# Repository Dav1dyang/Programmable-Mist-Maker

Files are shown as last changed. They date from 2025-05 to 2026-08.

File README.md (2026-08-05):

# Programmable Mist Maker

**Open-source, programmable ultrasonic mist maker kits** — by
[shuang cai](https://shuangcai.cargo.site/) & [David Yang](https://davidyang.work/) at ByProduct Lab.

📖 **[Documentation](https://docs.byproductlab.com/)** ·
🛒 **[Buy a kit](https://shop.byproductlab.com)** ·
📜 [OSHWA certified US002742](https://certification.oshwa.org/us002742.html) ·
✍️ [Build story on Hackster](https://www.hackster.io/dav1dyang/waste-into-wonder-making-programmable-mist-makers-fe3ae7)

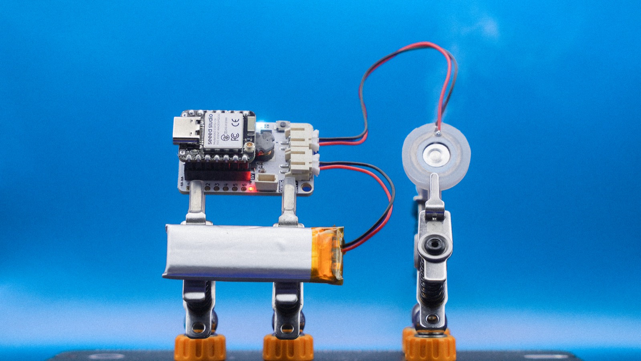
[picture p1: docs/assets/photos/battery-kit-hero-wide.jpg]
A Battery Kit board with a XIAO ESP32-C6 and a Li-Po cell, driving a piezo disc that is actively misting


Most mist-maker circuits online are undocumented black boxes. This project fills that
gap: tested reference circuits, full KiCad sources, an Arduino library, and honest
notes about what went wrong along the way — so creators, educators, and engineers can
explore mist as a material. First presented as a hands-on workshop at the
**Open Hardware Summit 2025**.

## The boards

| Board | Power | Best for | Status |
|---|---|---|---|
| [**Extension Kit**](variants/xiao-extension-kit/) | USB-C | First builds, desks, classrooms | V0.1 — hardware + firmware ready |
| [**Battery Kit**](variants/battery-kit/) | Li-Po + USB-C | Portable builds, installations | **V0.4.1 — in production, bench-validated** |
| [**Block Kit**](variants/block-kit/) | Li-Po + USB-C | Drop-in container UX, 14 LEDs | V0.1 — demoed at OHS 2026 |
| [**I2C MultiPack**](variants/i2c-multipack-kit/) | TBD | Multi-emitter installations | In design |
| [**Legacy V1.4**](legacy/v1-4/) | USB / Li-Po | Reproducing the original workshop kit | Shipped, frozen |

<p align="center">
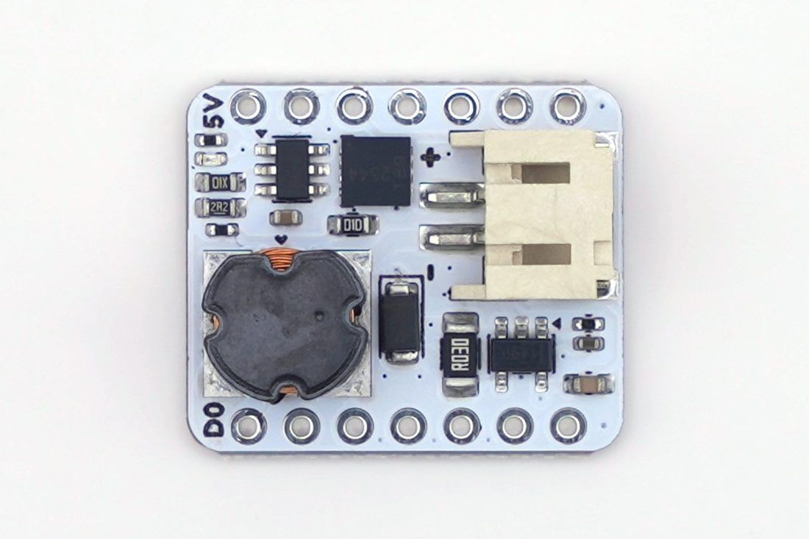
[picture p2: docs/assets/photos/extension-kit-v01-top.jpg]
Extension Kit V0.1, top side
  
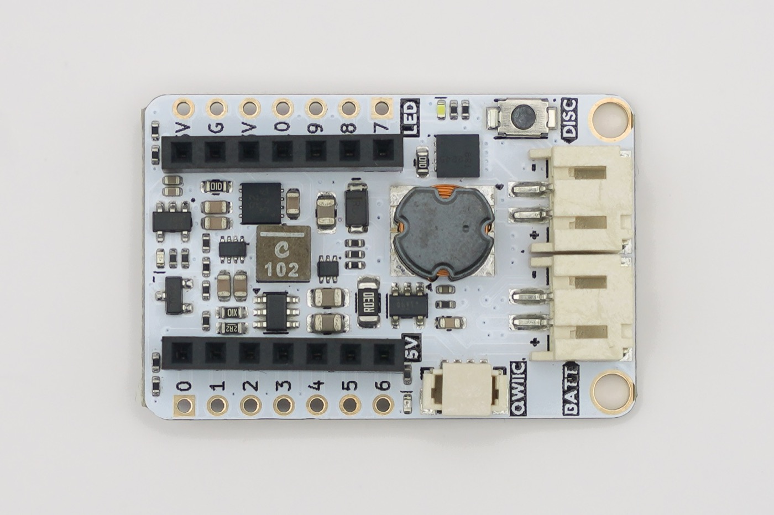
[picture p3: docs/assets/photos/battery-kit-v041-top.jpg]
Battery Kit V0.4.1, top side
  
</p>

<p align="center"><em>The two shipping boards: Extension Kit V0.1 (left) and Battery Kit V0.4.1 (right).</em></p>

Each variant folder has its own README with pin maps, an order-ready BOM + JLCPCB
production files, and build instructions. Board-by-board guides with **interactive
schematics** live on the [documentation site](https://docs.byproductlab.com/).

## Start here

1. **Pick a board** — the [Extension Kit](https://docs.byproductlab.com/boards/extension-kit/)
   is the easiest first build; the [Battery Kit](https://docs.byproductlab.com/boards/battery-kit/)
   cuts the cord. (Or [buy one assembled and tested](https://shop.byproductlab.com).)
2. **Flash the variant's BringUp sketch** to verify the hardware feature by feature.
3. **Install the [MistMaker Arduino library](https://github.com/owochel/MistMaker)** (v2.2+)
   and work through the examples: `Blink` → `Breath` → `WaterDetect` →
   `PhoneDemo` (control it from your phone).
4. **Smart home?** [`firmware-examples/home-assistant/`](firmware-examples/home-assistant/)
   joins Home Assistant with no code at all (ESPHome).

## How it works

An ESP32 drives a piezo disc at its **108.7 kHz** resonance through a MOSFET and a
3-legged tapped inductor — an autotransformer + LC tank that steps 5 V up to the
~80 Vpp the disc needs, while a current-sense amp lets the firmware detect the
disc and the water level on one ADC pin. The full story — atomization science, why
that strange inductor is everywhere in Shenzhen and nowhere at DigiKey, and a
verified alternative circuit — is at
[docs.byproductlab.com/how-it-works](https://docs.byproductlab.com/how-it-works/).

## Repo map

| Path | Contents |
|---|---|
| `variants/<board>/` | Per-board KiCad project, BOM, production files, BringUp firmware, enclosure |
| `legacy/v1-4/` | The original workshop kit, preserved as documented (incl. duck & UFO enclosure STLs) |
| `firmware-examples/` | ESPHome / Home Assistant configs |
| `docs/` | The [documentation site](https://docs.byproductlab.com/) (MkDocs), incl. `docs/assets/photos/` |
| `assets/` | Legacy V1.4 photos and the design-progress GIFs |

> [!NOTE]
> Reproducing the **legacy V1.4 board**? It has a few quirks the V0.x boards designed
> away (power sequencing, upload-while-misting) — fixes are preserved on the
> [Legacy V1.4 docs page](https://docs.byproductlab.com/boards/legacy-v1-4/).

## Use and care

> [!WARNING]
> Water + electronics + time = biology. Use distilled or clean tap water, clean the
> container regularly, and let cotton sticks dry between uses. Never run a disc
> dry for long, and never drive the circuit without a disc attached. Full notes in the
> [docs](https://docs.byproductlab.com/how-it-works/#use-and-care).

## License & credits

Open source under the **MIT License**, certified open source hardware
([OSHWA US002742](https://certification.oshwa.org/us002742.html)). Designed and
tested by [David Yang](https://davidyang.work/) and
[shuang cai](https://shuangcai.cargo.site/), inspired by community
reverse-engineering and YouTube teardowns — full reference list in the
[docs](https://docs.byproductlab.com/how-it-works/#research-references).

Parts of the documentation were drafted with AI assistance; all technical content is
validated against bench measurements and datasheets.

**Contact:** [contact@byproductlab.com](mailto:contact@byproductlab.com) ·
[@dav1dyang](https://www.instagram.com/dav1dyang/)

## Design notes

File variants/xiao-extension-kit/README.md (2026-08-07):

# Xiao Extension Kit — V0.1

The simplest way to drive mist from a [Seeed XIAO ESP32-C6](https://www.seeedstudio.com/Seeed-Studio-XIAO-ESP32C6-Pre-Soldered-p-6328.html): an expansion PCB that mounts directly on the XIAO. USB-C powered, no battery, no boost converter — just the piezo drive stage and an INA180 current-sense amp so your code can *feel* the disc working.

Great for: desks, breadboard experiments, classrooms, and anyone's first mist build.

📖 **[Full guide with interactive schematic](https://docs.byproductlab.com/boards/extension-kit/)** ·
🛒 **[Buy it assembled](https://shop.byproductlab.com/kits/extension-kit)**

Extension Kit V0.1, top side: tapped inductor bottom-left, PH-2.0 piezo connector on the right, header rows top and bottom

## What's in this folder

| Subfolder | Contents |
|---|---|
| [`hardware/`](hardware/) | KiCad project, schematic/assembly PDFs, BOM, JLCPCB production files |
| [`firmware/ExtensionKit_BringUp/`](firmware/ExtensionKit_BringUp/) | Per-feature test sketch — flash this first on a new board |
| `enclosure/` | 3D-printable demo enclosure (not published yet) |

## How it works

```
XIAO USB-C 5V ──┬─► UCC27511 gate driver ─► DMT10H009 MOSFET ─► 3-leg inductor ─► piezo disc
                │         ▲ D0: 108.7 kHz PWM                     (LC resonance boosts
                └─► 30 mΩ shunt ─► INA180A3 ─► D2 (analog)          5 V to ~80 Vpp)
```

- The ESP32 outputs a **108.7 kHz PWM** (the disc's resonant frequency) at 33% duty by default — the thermal sweet spot, not a hard ceiling ([why](https://docs.byproductlab.com/how-it-works/#the-resonant-drive-5-v-in-80-vpp-out)).
- The MOSFET switches the tapped-inductor + piezo loop; LC resonance boosts the 5 V rail to the ~80 Vpp the disc needs (measured on the Legacy V1.4 circuit; same topology here).
- The **INA180A3** (100 V/V) reads the voltage across a 30 mΩ shunt — 3.0 V per amp into D2. A dry disc draws visibly less than a wet one, which is how disc-presence and water-level detection work.

## Pin map

| XIAO pin | Net | Function |
|---|---|---|
| D0 | `MIST_PWM_3V3` | 108.7 kHz PWM to gate driver |
| D2 | `CS` | INA180A3 current-sense output (3.0 V/A) |
| D4 / D5 | SDA / SCL | I2C breakout — free for your sensors |

## Key components ([full BOM](hardware/production/bom.csv))

| Part | Role |
|---|---|
| UCC27511A gate driver | Clean, fast MOSFET gate edges at 108.7 kHz |
| DMT10H009LCG MOSFET | Switches the resonant loop |
| 3-legged tapped inductor (CD75) | LC voltage boost to ~80 Vpp |
| INA180A3 + 30 mΩ shunt | Analog current sense (3.0 V/A) |
| PH-2.0 connector | Piezo disc |

## Build your own

1. Order PCBs with the JLCPCB production files in [`hardware/`](hardware/) (SMT assembly recommended — everything except the connectors can be machine-placed).
2. Solder the PH-2.0 piezo connector and XIAO headers.
3. Mount a XIAO ESP32-C6.
4. Flash [`firmware/ExtensionKit_BringUp/`](firmware/ExtensionKit_BringUp/) and walk its serial checklist (`h` for help).
5. Install the [MistMaker library](https://github.com/owochel/MistMaker) (v2.2+) and try the examples: `Blink` → `Breath` → `WaterDetect` → `PhoneDemo`.

In library examples select the board with:

```cpp
MistMaker mist(MistMakerExtensionV01());
```

## Notes

- Power budget: a misting disc draws roughly 0.3–0.5 A from the 5 V USB rail — any normal USB port or charger is fine.
- Safety, cleaning, and known-issues notes live in the [root README](../../README.md).

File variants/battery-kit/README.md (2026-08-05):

# Battery Kit — V0.4.1

The portable, single-PCB "grab and go" Mist Maker: Li-Po battery + USB-C charging, full power path, piezo drive, current sensing, a button, a status LED — and **trustworthy battery monitoring**: since V0.4 the board routes the power mux's status pin to the XIAO (D8), so firmware knows whether it is running from USB or the cell and low-battery logic can never false-trigger while plugged in.

> **V0.4.1** is the July 2026 production revision (the boards in the shop): R22 → 220 kΩ widens the D8 USB-detect margin, R8 → pull-down means the ~5 V rail boots **off** (and deep sleep drops to ~0.25 mA), R7 → 5.1 kΩ dims LED2. Same pin map as V0.4. The [`hardware/`](hardware/) folder holds the as-fabbed V0.4.1 KiCad + production files, the design-review memos, and the acceptance-test protocol.

Great for: installations, performances, kits, and anywhere without a USB cable.

📖 **[Full guide with interactive schematic](https://docs.byproductlab.com/boards/battery-kit/)** ·
🧰 **[Enclosure & assembly](https://docs.byproductlab.com/boards/battery-kit-enclosure/)** ·
🛒 **[Buy it assembled](https://shop.byproductlab.com/kits/battery-kit)**

Battery Kit V0.4.1, top side: tapped inductor at center, QWIIC / DISC / BATT connectors and the button along the right edge

## What's in this folder

| Subfolder | Contents |
|---|---|
| [`hardware/`](hardware/) | As-fabbed V0.4.1 KiCad project, schematic PDF, BOM, JLCPCB production files, design reviews + acceptance protocol |
| [`firmware/BatteryKit_BringUp/`](firmware/BatteryKit_BringUp/) | Bring-up sketch — flash first; hold the button ≥ 1.5 s for the **automated self-test** |
| [`firmware/DutySweep_Test/`](firmware/DutySweep_Test/) | Duty→current characterization tool (the data behind the 50% default) |
| `enclosure/` | 3D-printable demo enclosure — print files not published yet; the build is documented step by step in [Enclosure & Assembly](https://docs.byproductlab.com/boards/battery-kit-enclosure/) |

## How it works

```
USB-C ─► LP4060 charger ─► Li-Po ─┐
                                  ├─► TPS2116 power mux ─► AP7361C 3V3 LDO ─► XIAO
USB-C 5V ─────────────────────────┘
                                  └─► TPS61023 boost (EN = D3) ─► 5V5 rail
5V5 ─► UCC27511 ─► DMT10H009 MOSFET ─► 3-leg inductor ─► piezo disc
        ▲ D0: 108.7 kHz PWM
5V5 current ─► 30 mΩ shunt ─► INA180A3 ─► D2 (analog)
VBAT ─► ½ divider ─► D1 (analog)
```

- **Power path:** the TPS2116 mux picks USB when present, battery otherwise; the LP4060 charges the Li-Po from USB-C.
- **Piezo rail:** the TPS61023 boost (enabled by D3) makes a stable 5.5 V from either source. Turn it off when idle — it's the single biggest standby drain.
- **Sensing:** INA180A3 + 30 mΩ shunt → analog D2 for disc/water detection; battery divider → D1 for the fuel gauge.

## Pin map

| XIAO pin | Net | Function |
|---|---|---|
| D0 | `MIST_PWM_3V3` | 108.7 kHz PWM to gate driver |
| D1 | `D1_BATT_VOLTAGE` | Battery voltage via ½ divider (V0.3+) |
| D2 | `D2_CS` | INA180A3 current-sense output |
| D3 | `D3_TPS_EN` | TPS61023 boost enable (HIGH = 5V5 on) |
| D4 / D5 | `D4_SDA` / `D5_SCL` | I2C + Qwiic connector |
| D6 | `D6_BUTTON` | Button, active HIGH (10k pull-down on PCB) |
| D7 | `D7_LED` | Status LED |
| D8 | `D8_ST` | **Power-mux status (V0.4+):** HIGH = on USB, LOW = on the cell — plain `INPUT`, no internal pull |
| D9–D10 | — | Spare breakout |

## Key components ([full BOM](hardware/))

| Part | Role |
|---|---|
| LP4060B5F | Single-cell Li-Po USB-C charging |
| TPS2116DRLR | USB/battery power mux |
| AP7361C-3.3 | 3V3 LDO |
| TPS61023 | 3V→5.5V boost for the piezo rail |
| UCC27511A + DMT10H009LCG | Gate driver + MOSFET, 108.7 kHz switching |
| 3-legged tapped inductor (CD75) | LC voltage boost to ~80 Vpp |
| INA180A3 + 30 mΩ shunt | Analog current sense (3.0 V/A) |
| TS-1088 tactile switch, white LED | User button + status |
| Qwiic / JST-SH 4-pin | I2C expansion |

## Battery monitoring & graceful shutdown

D1 reads the pack through an equal-resistor divider (ratio 2.0). On USB the node tracks the *charger*, not state-of-charge — which is why V0.4 added the D8 source sense, and why on a V0.3 board you should call `disableBattery()`. Guidance, measured under load (valid on the cell):

| Voltage | Meaning | Firmware should |
|---|---|---|
| 4.2 V | Full | — |
| ~3.7 V | Nominal | — |
| < 3.45 V | Low | Warn (LED blink / UI banner) |
| < 3.20 V | Critical | Mist off → boost off → deep sleep |

The [MistMaker library](https://github.com/owochel/MistMaker) (v2.1+) wraps this and gates it on the D8 source sense — `batteryState()` returns `CHARGING` on USB and only ever `LOW`/`CRITICAL` on the cell: `batteryState()`, `batteryPercent()`, `usbPresent()`, `shutdown()`. The library README's battery section shows the full graceful power-off pattern (two consecutive critical readings, radio off, deep sleep).

## Build your own

1. Order PCBs with the JLCPCB production files in [`hardware/`](hardware/) (SMT assembly recommended).
2. Solder the XIAO sockets, piezo connector (PH-2.0), and battery connector (PH-2.0).
3. Snap in a XIAO ESP32-C6, connect a 1S Li-Po (500 mAh+ recommended).
4. Flash [`firmware/BatteryKit_BringUp/`](firmware/BatteryKit_BringUp/) and hold the button ≥ 1.5 s (or send `a`): the **automated self-test** checks reset reason, power-source sense, battery divider, current-sense zero, boost gating, and a classified drive burst, then prints a PASS/FAIL report. Finish with the manual steps it lists (`u` power-source test, USB unplug/replug handoff).
5. Install the MistMaker library (v2.1+) and try the examples — select the board with:

```cpp
MistMaker mist(MistMakerBatteryKitV041());  // V0.4: same preset; V0.3: MistMakerBatteryKitV03()
```

## Notes

> [!WARNING]
> Li-Po safety: only use protected 1S cells, never charge unattended, and keep the cell away from the water container. For workshops in venues that restrict lithium batteries, run this board from USB-C only — it works fine without a cell.

- Develop with the battery connected or not — the TPS2116 power mux always prefers USB when present, so serial enumeration and uploads just work (this fixes the legacy V1.4 power-sequence quirk).
- Safety, cleaning, and known-issues notes live in the [root README](../../README.md).

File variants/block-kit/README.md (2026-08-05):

# Block Kit — V0.1

A 3-PCB build of the Programmable Mist Maker designed around a modular "drop-in container" UX: insert the magnetic water container and misting starts automatically; lift it off and it stops. A single button provides manual override and LED brightness control. Demoed at the Open Hardware Summit 2026.

📖 **[Full guide](https://docs.byproductlab.com/boards/block-kit/)**

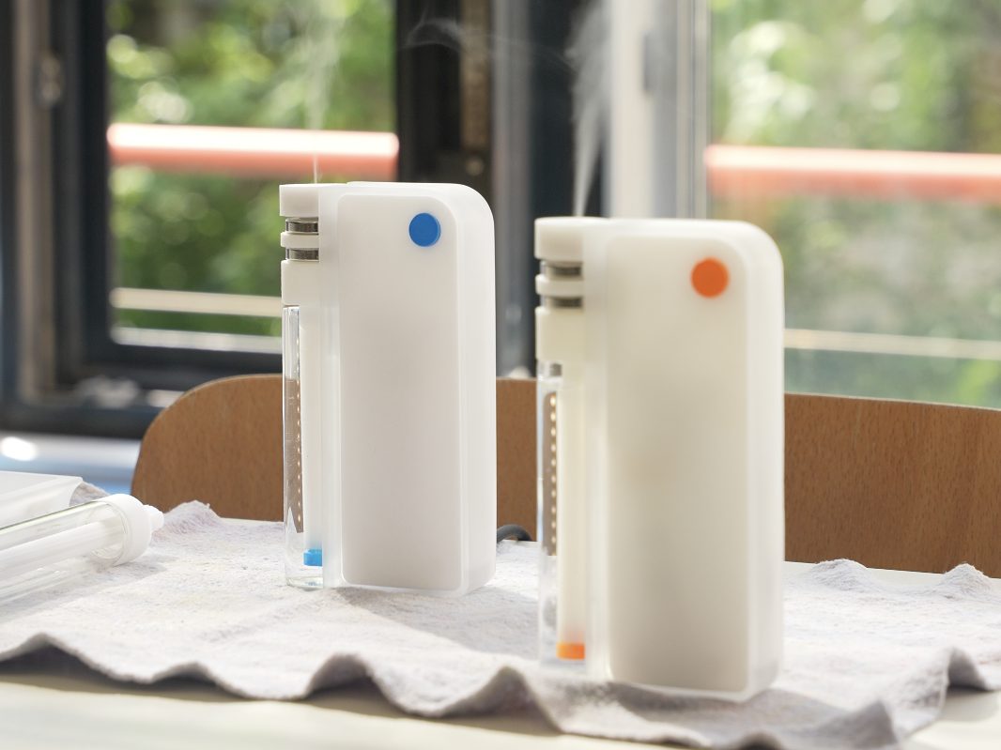
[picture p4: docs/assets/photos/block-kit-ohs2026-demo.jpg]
Two white Block Kit units standing on a windowsill at a demo desk, water containers docked and mist rising, with trees visible through the window behind


## What's in this folder

| Subfolder | Contents |
|---|---|
| [`hardware/`](hardware/) | KiCad projects for the three PCBs (Driver, Mist & LED, Button) plus assembly notes |
| [`firmware/BlockKit_Production/`](firmware/BlockKit_Production/) | Daily-use firmware — full Phase A UX + WiFi onboarding + OTA + web UI for config and debug |
| [`firmware/BlockKit_BringUp/`](firmware/BlockKit_BringUp/) | Minimal per-feature test sketch — flash this when something on the bench feels off |
| `enclosure/` | (planned) 3D-printable shell |

## Key components

- **MCU:** Seeed XIAO ESP32-C6 (same as V1.4)
- **Mist drive:** TPS61023 3V3→5V boost + UCC27518 level shifter + DMT10H009LCG MOSFET → 108.7 kHz / 50 % PWM on a 16 mm ceramic disc
- **Power:** USB-C charging via LP4068BF, single-cell Li-Po; TPS2116DRLR mux switches between USB and battery; AP7361C 3V3 LDO
- **Sensing:** INA180A3 + 30 mΩ shunt for piezo current; reed switch for magnetic container-present detection
- **LEDs:** IS31FL3731 charlieplex driver with 14 LEDs (8 + 6) on the Matrix B side
- **Input:** single B3AL-1002P tactile switch on a dedicated PCB

## Bring-up sequence

1. Assemble the three PCBs and verify the inter-board harness (see [`hardware/README.md`](hardware/README.md)).
2. Apply the V0.1 reed-to-D10 blue-wire rework.
3. Flash `firmware/BlockKit_Production/BlockKit_Production.ino` — see [`firmware/BlockKit_Production/README.md`](firmware/BlockKit_Production/README.md) for full install steps (incl. the WiFiManager dependency for OTA + web UI). If a hardware feature looks broken, flash [`firmware/BlockKit_BringUp/`](firmware/BlockKit_BringUp/) first to verify each peripheral in isolation.
4. Walk the bring-up checklist in the firmware README.
5. With scope mode (`s`) on, gather a Serial Plotter trace of `mean_mA, var_mA2` for: full water, low water, dry disc, no disc. These traces drive the Phase B water-level classifier.

## Safety and care

The shared safety notes (cleaning, mineral buildup, what water to use) live in the [root README](../../README.md). They apply to every variant.

## Status

- ✅ V0.1 hardware: 3 PCBs designed
- ✅ Phase A firmware: this folder
- ⏳ Phase B firmware: water-level classifier from real bench data
- ⏳ V0.2 hardware: VBAT voltage divider for graceful low-battery stop, optional INA180 filter-corner raise
- ⏳ Enclosure: pending

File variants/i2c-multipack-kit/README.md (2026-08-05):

# I2C MultiPack Kit

A multi-emitter variant that drives several piezo discs from a single XIAO ESP32-C6 via an I2C-controlled bank.

**Status:** in design — the next variant up. Chainable I2C mist drivers (6 PWM channels per node) so one controller can orchestrate many discs. Hardware, firmware, and enclosure files will land here as the variant is brought up.

📖 **[What's planned](https://docs.byproductlab.com/boards/i2c-multipack/)** — and if you'd build something with it, [tell us](mailto:contact@byproductlab.com).

Safety, cleaning, and known-issues notes live in the [root README](../../README.md).

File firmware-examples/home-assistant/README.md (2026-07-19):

# Mist Maker × Home Assistant

Two ways to put a Programmable Mist Maker on your smart-home dashboard. Both expose the mist as a **dimmable light entity** (on/off + level slider), battery sensors, and water/disc status — and both shut the mist down gracefully when the battery runs low.

## Option A — ESPHome (recommended, no code)

1. Install the **ESPHome Builder** add-on in Home Assistant.
2. New Device → paste [`esphome-mistmaker.yaml`](esphome-mistmaker.yaml) → set your WiFi secrets.
3. Flash the XIAO ESP32-C6 over USB once; updates are over-the-air after that.
4. HA auto-discovers the device. Done.

The YAML targets the **Battery Kit V0.3**. For the Extension (BFF) V0.2, delete the boost switch, battery sensors, and button blocks.

## Option B — Arduino + MQTT

Prefer to stay in the Arduino ecosystem (or to customize behavior)? The **`HomeAssistant_MQTT`** sketch was retired from the library's curated examples in v2.2 — download it from the [v2.1.0 release](https://github.com/owochel/MistMaker/releases/tag/v2.1.0) (`examples/HomeAssistant_MQTT/`), then:

1. Run an MQTT broker (the Mosquitto add-on) and HA's MQTT integration.
2. Open the sketch, fill in WiFi + broker credentials, flash.
3. The sketch publishes MQTT Discovery configs — the device appears automatically with mist light, battery %, and water-status entities, plus offline detection via LWT.

## Automation ideas

- Mist on sunset, off at bedtime (`light.turn_on` with `brightness`)
- Notify your phone when water runs low (`water == "low"`)
- Auto-stop when battery < 15% (the firmware hard-stops at 3.2 V regardless)

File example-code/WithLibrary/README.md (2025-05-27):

# This example will only work if you installed the library.

## 📦 Library Installation

### 🔗 Option 1: Install via Arduino IDE using GitHub URL

1. In Arduino IDE, go to:  
   `Sketch > Include Library > Add .ZIP Library...`

2. Paste this URL into your browser and download the ZIP file:  
   [Download Library ZIP](https://github.com/owochel/MistMaker/archive/refs/heads/main.zip)

3. Select the downloaded ZIP file in Arduino IDE.

4. You're done! Now you can access example code via:  
   `File > Examples > MistMaker > SimpleControl`
   or
   `File > Examples > MistMaker > Blink`

---

### 💻 Option 2: Clone or Copy into Libraries Folder (Advanced)

Clone this subfolder manually and place it inside your Arduino libraries directory:

```bash
git clone https://github.com/owochel/MistMaker.git
cp -r MistMaker ~/Documents/Arduino/libraries/
```

Note: Your library location may be different. [Look at Arduino Support Article here](https://support.arduino.cc/hc/en-us/articles/4415103213714-Find-sketches-libraries-board-cores-and-other-files-on-your-computer) to see how you can locate your Libary folder.

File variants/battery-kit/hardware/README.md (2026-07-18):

# Battery Kit V0.4.1 — Hardware

As-fabbed files for the **July 2026 production run** (the boards sold in the
shop). The KiCad project keeps the `V0-4` file name — the V0.4.1 changes are
edits inside it, and the production set here is the exact export that run was
built from.

| File | What |
|---|---|
| [`kicad/`](kicad/) | KiCad 10 project, **as-fabbed V0.4.1** (schematic + PCB + custom symbol/footprint libs) |
| [`MistMaker-Battery-Kit_V0-4-1_SCH.pdf`](MistMaker-Battery-Kit_V0-4-1_SCH.pdf) | Schematic PDF (plotted from the project) |
| [`production/MistMaker-Battery-Kit_0-4-1.zip`](production/) | Gerbers for JLCPCB — the ordered fileset |
| [`production/bom.csv`](production/bom.csv) | BOM with LCSC part numbers (for JLCPCB SMT assembly) |
| [`production/positions.csv`](production/positions.csv) | Pick-and-place positions |
| [`production/designators.csv`](production/designators.csv) / [`netlist.ipc`](production/netlist.ipc) | Designator map + IPC netlist from the same export |
| [`V04-Acceptance-Test_2026-07-04.md`](V04-Acceptance-Test_2026-07-04.md) | Per-board acceptance protocol (~20 min) — the automated slice runs in `BatteryKit_BringUp`'s self-test |
| [`PCB-Review_Battery-Kit-V0-4_2026-07-03_board-in-hand.md`](PCB-Review_Battery-Kit-V0-4_2026-07-03_board-in-hand.md) | Board-in-hand design review (ST sense verified, D8 margin analysis) |
| [`PCB-Review_Battery-Kit-V0-4_2026-06-22.md`](PCB-Review_Battery-Kit-V0-4_2026-06-22.md) | Pre-order design + procurement review |
| [`Duty-Cycle-Research_2026-07-03.md`](Duty-Cycle-Research_2026-07-03.md) | Measured duty→mist curve: why the 50% default, where the real maximum is (~70%) |

<!-- PHOTO: V0.4.1 assembled board, top — hardware close-up for this page -->

## Version changes

**V0.4.1** (July 2026 production run, 15 pcs — **current**):

- **R22 150 kΩ → 220 kΩ** — D8's USB-detect logic-high moves ~2.6 V → ~3.1 V,
  widening the margin over the XIAO's V<sub>IH</sub> from 0.2 V to 0.66 V (the one
  bench-marginal number population spread could have tipped across a batch).
- **R8 pull-up → pull-down (to GND)** — the ~5 V boost rail now boots **OFF**
  (LED2 dark until firmware raises D3) and deep-sleep drain drops from
  ~0.3–0.5 mA to **~0.25 mA**. Firmware-compatible: every drive path sets EN
  explicitly.
- **R7 2 kΩ → 5.1 kΩ** — LED2 dimmed to a sane brightness.
- Still deferred to V0.5: delete C14 (redundant bulk), copy the Extension's U4
  100 nF bypass placement, brighter LED3, footprint-name hygiene (IC2 carries a
  `TPS62932` footprint name; the part is a TPS2116 — electrically correct).

**V0.4** (assembled 2026-06, 5-pc prototype):

- **TPS2116 ST (mux status) routed to XIAO D8** via an R15 pull-up + R21/R22
  divider — HIGH = on USB, LOW = on the cell. The same node drives
  Q1 to disable the 3V3 LDO whenever USB is present, so the board LDO and the
  XIAO's own regulator never fight. This is the hardware fix for V0.3's
  false low-battery shutdowns on USB.
- **Charge current 500 mA → ~196 mA** (R6 = 5.1 kΩ) — keeps the SOT-23-5
  charger comfortably inside its thermal budget.

**V0.3:**

- **Battery voltage divider on D1** (`D1_BATT_VOLTAGE`, ratio 2.0) — enables the
  fuel gauge + graceful low-battery shutdown in firmware.
  (V0.3 KiCad files: see this folder's git history.)

## Ordering from JLCPCB

1. Upload `MistMaker-Battery-Kit_0-4-1.zip` (defaults fine; 1.6 mm).
2. Enable **SMT assembly**, upload `bom.csv` + `positions.csv`.
3. Hand-solder afterwards: XIAO sockets, PH-2.0 piezo + battery connectors.
4. Incoming boards: flash `BatteryKit_BringUp`, run the **automated self-test**
   (hold the button ≥ 1.5 s), then the manual steps in
   [`V04-Acceptance-Test_2026-07-04.md`](V04-Acceptance-Test_2026-07-04.md).

If you edit the schematic before ordering, re-export BOM + positions + gerbers
**as one set** (Fabrication Toolkit) — never mix a fresh zip with an old BOM.

The KiCad project uses the bundled `Mist_Custom` symbol and `Mist_Library.pretty`
footprints (paths in `sym-lib-table` / `fp-lib-table` are project-relative — it
opens standalone).

## Key datasheets

- [TPS61023](https://www.ti.com/lit/ds/symlink/tps61023.pdf) — 5.5 V boost converter
- [TPS2116](https://www.ti.com/lit/ds/symlink/tps2116.pdf) — power mux (USB/battery)
- [LP4060B5F](https://datasheet.lcsc.com/lcsc/1912111437_LOWPOWER-LP4060B5F_C517259.pdf) — Li-Po charger
- [INA180](https://www.ti.com/lit/ds/symlink/ina180.pdf) — current-sense amp (A3 = 100 V/V)
- [UCC27511A](https://www.ti.com/lit/ds/symlink/ucc27511a.pdf) — gate driver
- [DMT10H009LCG](https://www.diodes.com/assets/Datasheets/DMT10H009LCG.pdf) — MOSFET
- [Seeed XIAO ESP32-C6](https://wiki.seeedstudio.com/xiao_esp32c6_getting_started/)

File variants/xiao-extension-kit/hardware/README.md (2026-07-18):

# Extension Kit V0.1 — Hardware

| File | What |
|---|---|
| [`kicad/`](kicad/) | KiCad 10 project (schematic + PCB) |
| [`MistMaker-Seeed-Extension_V0-1_SCH.pdf`](MistMaker-Seeed-Extension_V0-1_SCH.pdf) | Schematic PDF — read this first |
| [`MistMaker-Seeed-Expansion-V0.1__Assembly.pdf`](MistMaker-Seeed-Expansion-V0.1__Assembly.pdf) | Assembly drawing |
| [`production/XiaoMistMaker_V0-1.zip`](production/) | Gerbers for JLCPCB |
| [`production/bom.csv`](production/bom.csv) | BOM with LCSC part numbers (for JLCPCB SMT assembly) |
| [`production/positions.csv`](production/positions.csv) | Pick-and-place positions |

## Ordering from JLCPCB

1. Upload `XiaoMistMaker_V0-1.zip` (defaults are fine; 1.6 mm, any color).
2. Enable **SMT assembly**, upload `bom.csv` + `positions.csv`.
3. Hand-solder afterwards: PH-2.0 piezo connector, XIAO headers.

## Key datasheets

- [INA180](https://www.ti.com/lit/ds/symlink/ina180.pdf) — current-sense amp (A3 = 100 V/V)
- [UCC27511A](https://www.ti.com/lit/ds/symlink/ucc27511a.pdf) — single-channel gate driver
- [DMT10H009LCG](https://www.diodes.com/assets/Datasheets/DMT10H009LCG.pdf) — MOSFET
- [Seeed XIAO ESP32-C6](https://wiki.seeedstudio.com/xiao_esp32c6_getting_started/)

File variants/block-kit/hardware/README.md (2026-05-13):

# Block Kit — Hardware

The Block Kit is a 3-PCB stack. Each PCB has its own folder so KiCad projects, BOMs, and exported PDFs can evolve independently.

```
hardware/
├── driver-pcb/         # Block-Kit-V0-1            (XIAO socket, USB-C, charger, boost, MOSFET drive, INA180)
├── mist-and-led-pcb/   # Block-Kit-Mist-and-LED    (IS31FL3731, 14 LEDs, reed switch, piezo connector, Qwiic)
└── button-pcb/         # Block-Kit-Button          (single B3AL-1002P momentary switch)
```

## Inter-board wiring (V0.1)

The Driver PCB exposes two socket headers, `J7` and `J8`, that mate with the Mist & LED PCB. The Button PCB connects through a WAGO-2059 to the `SW+`/`SW−` pads on the Mist & LED PCB.

| Net | From | To | Notes |
|---|---|---|---|
| `+3V3` / `GND` / `+5V5` | Driver PCB | Mist & LED PCB | Power for IS31FL3731 (3V3) and piezo MOSFET drive (5V5) |
| `D0_MIST_PWM_5V5` | Driver PCB | Piezo (J1 on Mist & LED) | JP01 closed by default |
| `D10_REED` | Driver PCB | Reed switch SW1 | **V0.1 rework required:** blue-wire reed pads to a D10 breakout (see below) |
| `D2_C6` | INA180A3 (Driver) | n/a | Local on Driver PCB |
| `D3_LED` | Driver PCB | TPS61023 EN + LED2 (red) | Indicator LED lights when boost is enabled |
| `D4_SDA` / `D5_SCL` | Driver PCB | IS31FL3731 + Qwiic J6 | Shared I2C bus |
| `D6_BUTTON` | Driver PCB | Button PCB via SW+/SW− → J2 | Active-HIGH, 10 kΩ pull-down on Driver PCB |
| `D7_LED` | Driver PCB | LED3 (white) | Local on Driver PCB |

## V0.1 rework — reed switch on D10

The original V0.1 schematic routes the reed switch through `J2` into the button series circuit. The firmware needs the reed and button on **separate** GPIOs. D10 is a free pin on the XIAO ESP32-C6 (GPIO 18), physically opposite the mist-PWM pin (D0) on the XIAO footprint, so it stays well away from any PWM crosstalk. For V0.1 boards:

1. Cut the trace from the reed switch to `SW+`/`SW−`.
2. Blue-wire one reed pad to a `D10` breakout (via J7/J8 socket or the Driver PCB's D10 test point).
3. Leave the other reed pad on GND.

D1 is left at its schematic role (alt-PWM via JP02) and JP02 should remain open as documented.

Document the actual rework with a photo in the next commit.

## V0.2 hardware items

- Battery voltage divider: 1 MΩ + 1 MΩ from `VBAT` to a freed ADC pin so firmware can warn at ~3.5 V and gracefully stop at ~3.3 V. Freeing a pin likely means moving the reed switch to an I2C IO expander.
- Optional: raise the INA180 RC filter corner from ~159 Hz to ~400 Hz (drop the 1 µF cap to ~0.4 µF, or drop the 1 kΩ resistor to ~400 Ω) if Phase A bench data shows the current variance signal is weak.
- Split-wire the reed and button properly in the schematic (no blue-wire rework needed).

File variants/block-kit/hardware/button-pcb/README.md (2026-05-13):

# Block Kit Button PCB (V0.1)

A single-component breakout: one B3AL-1002P momentary tactile switch routed to a WAGO-2059 connector. Plugs into the `SW+`/`SW−` pads on the Mist & LED PCB.

Drop the KiCad project here:

```
Block-Kit-Button-PCB-V0-1.kicad_pro
Block-Kit-Button-PCB-V0-1.kicad_sch
Block-Kit-Button-PCB-V0-1.kicad_pcb
Block-Kit-Button-PCB-V0-1.kicad_prl
bom.csv
2026-05-02_Block-Kit-Button-PCB-V0-1_SCH.pdf
2026-05-02_Block-Kit-Button-PCB-V0-1_BRD.pdf
```

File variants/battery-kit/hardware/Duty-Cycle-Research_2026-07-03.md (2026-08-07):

# Does mist output max out at 50% PWM duty? — research memo

**Date:** 2026-07-03 **Method:** deep-research sweep (5 search angles, 19 sources
fetched, 25 claims adversarially verified 3-vote; refuted claims discarded) +
**first-party bench sweep on the physical Battery Kit V0.4** (DutySweep_Test,
disc in water, USB power).
**Board context:** single N-MOSFET (UCC27511A-driven Q4) switching one leg of a
CD75-style 3-terminal autotransformer (L1) from the ~5 V rail; piezo disc across
the other legs forms the resonant tank (~80 Vpp at 108.7 kHz).

---

## Verdict

**"Mist maxes out at 50% duty" is FALSE for this topology — but "cap the duty
at 50%" is still the right rule.** The bench sweep showed mist *increasing*
past 50%, and the topology-aware sources agree it can. What actually peaks at
50% is *efficiency*: past it, input current grows superlinearly, the
autotransformer saturates and heats, soft switching is lost, and (on USB) the
supply browns out. 127/255 is the efficiency/stability knee — the correct
default operating cap, not a physical output ceiling.

## Why the classic "50% is optimal" argument doesn't bind this board

The textbook argument is solid **for what it assumes**: the fundamental of a
rectangular pulse train of *fixed amplitude A* is ∝ `A·sin(π·D)`, maximal at
exactly D = 0.5 [1][2], and a resonant tank responds almost only to the
fundamental (tank-current THD ≈ 5% at loaded Q = 2.5 [3]; the disc voltage on a
commercial mist board measures near-sinusoidal [4]). Under those premises,
mist-vs-duty is a broad hump symmetric about 50%.

**The premise that fails here is "fixed amplitude."** This board is a
flyback-style single-switch drive: the drain isn't clamped to a rail — it
*rings up* during the off-time, and the ring amplitude depends on how much
energy the on-time stored in L1. Longer on-time → more stored energy → bigger
swing. The verification pass flagged exactly this: the sin(πD) formula
"strictly assumes a voltage-stiff rectangular drain waveform; the real
single-switch drain node rings during off-time and its waveform shape is
itself duty-dependent" — and fundamental-only analyses err by up to ~60% at
low loaded Q (Kazimierczuk & Puczko, IEEE TCAS 1987 [5]).

Two topology-aware sources predict output *rising* past 50%:
- **Re-tuned Class-E analysis** (hardware-validated): output grows
  monotonically with duty when the network follows (V_out 2.1 → 6.4 → 10.4 V
  at D = 0.25/0.5/0.75), at the cost of falling efficiency and steeply rising
  switch stress [6].
- **S.C. Johnson patent US 6,439,474** — the *same* single-FET
  tapped-autotransformer piezo atomizer circuit — uses gate pulse width
  (~19% up to ~68–78% duty) precisely as its **amplitude control** [7].

## The bench data (V0.4, 2026-07-03) — the deciding evidence

The research's open questions asked for exactly this measurement; we have it:

| duty % | drive current | observation |
|---|---|---|
| 18–50% | 170 → 225 mA (near-plateau) | resonant regime; mist rises; best mist/W |
| 56% | 314 mA | mist still rising |
| 62% | 485 mA | **L1 hot to touch** — saturation onset |
| 69% | 783 mA | superlinear current = saturation + lost soft switching |
| 75% | 1095 mA (≈1.5 A total on VBUS) | mist still visibly rising → **USB VBUS sag → TPS2116 drops USB (<4.0 V PR1) → brownout reset** (2×, reproducible) |

Mist output: **monotonically increasing to the crash point** (operator
observation) — consistent with [6][7], contradicting the fixed-amplitude
sin(πD) peak. Input power at 75% ≈ 5× the 50% point for a visibly modest mist
gain: the efficiency knee is real even though the output peak is not.

## Why commercial practice still sits at 50%

Microchip's ~117 kHz single-MOSFET nebulizer reference design (AN2265) drives
the FET at a **fixed 50% duty** and tunes *frequency* (90–150 kHz sweep) to
find transducer resonance [8]; teardowns of commodity 5 V mist modules show
the same square-ish OTP-MCU gate drive [4]. Duty is a poor throttle past 50%
(all pain, thin gain); frequency/amplitude are the professional knobs. A 1 MHz
Class-E study likewise recommends D = 0.5 as the design point — off it, ZVS is
lost and switching losses rise (98.4% efficiency at D = 0.5 with optimum load)
[9] — matching our heat observations.

## Expected curves for this board (synthesis)

- **Drive current vs duty:** near-flat plateau through the resonant regime
  (~18–50%), then superlinear growth (saturation + hard switching) — measured ✓.
- **Mist vs duty:** rising through 50% and continuing to rise slowly while
  current explodes; practical end = supply collapse (USB ~75%) or thermal
  limit (L1), not an output peak.
- **Mist-per-watt vs duty:** peaks at/below 50% and collapses beyond — this is
  the curve the 127 cap actually optimizes.

## Practical guidance

> **Superseded on point 1 (2026-08):** the library default moved to
> `dutyMax = 85` (33%) in MistMaker v2.6 after bench testing found it gives a
> good amount of mist with L1 staying cool on long runs. That is consistent with
> this sweep's mist-per-watt finding above (peaks at or below 50%) — it moves the
> default toward that peak rather than away from it. The rest of this memo stands
> as measured; it is kept unedited as the 2026-07-03 record.

1. **Keep `dutyMax = 127` as the library default** (efficiency, USB budget,
   L1 thermals, brownout margin).
2. A supervised **"turbo" band ~143–160 (56–63%)** exists for short bursts on
   a strong supply — watch L1 temperature; DutySweep_Test now aborts >600 mA.
3. If more mist is ever a product requirement, the honest levers are **rail
   voltage** (boost 4.95 → 5.5 V via R12) and **frequency fine-tuning to the
   disc's true resonance** (AN2265-style sweep — a good future library
   experiment), not duty.
4. Open question worth a scope session: drain waveform vs duty (does ring-back
   clip into the next on-time past 50%?), and whether co-tuning frequency with
   duty recovers output more efficiently ([7]'s approach).

## Sources

[1] S. Smith, *The Scientist & Engineer's Guide to DSP*, ch. 13 — dspguide.com/ch13/4.htm
[2] UIUC Physics 406 lecture notes, Fourier analysis of rectangular waves (duty-dependent harmonics, DC offset >50%)
[3] Spirov et al., *Eng. Proc.* 122(1):11 (2026) — square-wave-fed series resonant tank, THD vs Q, FHA limits
[4] T.K. Hareendran, EDN "Mist maker" teardown — commodity 5 V module, near-sine disc voltage
[5] Kazimierczuk & Puczko, IEEE Trans. Circuits & Systems (1987), DOI 10.1109/TCS.1987.1086114 — exact Class-E analysis at any Q
[6] Frequency-domain re-tuned Class-E analysis, hardware-validated (ShanghaiTech, metal.shanghaitech.edu.cn/publication/J5.pdf) — output monotonic in D when re-tuned
[7] US Patent 6,439,474 B2 (S.C. Johnson) — tapped-autotransformer piezo atomizer, pulse width as amplitude control
[8] Microchip AN2265 — vibrating-mesh nebulizer reference design, fixed 50% duty, frequency-tuned
[9] "Design and Analysis of 1 MHz Class-E Power Amplifier for Load and Duty Cycle Variations" (IRF510 prototype)

*Discarded in verification (do not cite): the claim that the 1 MHz Class-E
duty sweep showed output falling both sides of 50% (refuted 0–3); its specific
efficiency-vs-duty percentages (refuted 0–3); "50% has zero DC content
uniquely" as stated (refuted on technicality). The patent's >50% amplitude
claim passed only 2–1 (design assertion, unmeasured) — our bench data is the
stronger evidence on that point.*

---
---

# PART 2 — The full curve: Mist(D), measured and modeled (same day, complete)

**Bench campaign (2026-07-03, V0.4 + Extension V0.1, DutySweep_Test v3):**

| Supply | Result |
|---|---|
| Laptop USB + V0.4 (cell charging) | power CUT (~1.5 A port breaker) at ~75% duty — `reset: power-on`, not brownout |
| Laptop USB + Extension | full range 0→90%; apparent current "rollover" at 87–90% was VBUS sag, not the tank |
| 2 A wall brick + Extension | full range; drive current pinned at the **~1.1 A ADC ceiling** from 75% |
| 2 A wall brick + V0.4 (no cell) | inline meter read **2.1 A total (~1.9 A drive) at 80–85%** → brick fold-back → power cut. The boards' own sensor ceiling is the ESP32 ADC (~1.1 A), on both variants |
| Charged cell (4.02 V rest) + V0.4 | reached **exactly 70%** (822 mA drive ≈ 1.34 A from the cell), then the 3.5 V loaded floor; sag staircase gives **total source resistance ≈ 0.40 Ω** |
| 2 A wall brick + V0.4 **with cell attached** | still reset after the 80% step — **the cell cannot catch a brick fold-back at ~2 A**: the TPS2116's ~1.3 ms break-before-make gap vs ~30–40 µs of capacitor hold-up (42 µF @ 2 A), with the boost dragging the rail down during the gap. Cell sat untouched at 4.22–4.25 V throughout. **V0.4 hard ceiling ≈ 80% duty on any realistic supply** — comfortably above the 70% mist peak, so no operational loss |

**Operator mist observations (the output axis):** onset threshold — large
jump between 10% and 20% duty; steady rise through 50–65%; **visual maximum
at ~70% (duty 178)**; smaller at 80% and 90%; unstable/intermittent
("sometimes bigger, sometimes smaller") above ~75% on both laptop and brick.

## The model (deep-research pass 2: drive side verified, atomization side fitted)

```
Mist(D) = k · max(0, A(D) − A_th)^n        valid below D_unstable ≈ 0.75
A(D)    = a · D · (1 − D)^q
```

| Parameter | Meaning | Value from bench |
|---|---|---|
| `A_th` | capillary-wave atomization onset amplitude — below it, ripples but no droplets | crossed at **D ≈ 0.12–0.15** (the 10→20% jump) |
| `q` | ring-back clipping severity (how hard truncating the resonant half-period kills delivered amplitude) | peak at D\* = 1/(1+q) = 0.70 → **q ≈ 0.43** |
| `n` | super-threshold atomization-rate exponent | **free fit** — the literature claims (incl. onset-amplitude data and Faraday f/2 mechanism) could not be adversarially verified this run (infrastructure errors, not refutations); treat as mainstream-but-uncited |
| `D_unstable` | onset of intermittency | **≈ 0.75** observed |

**Drive-side physics, verified 3-0 against primary sources:**
- Unsaturated single-switch flyback/ringing-choke: `I_pk = V·t_on/L`, energy
  per cycle `½·L·I_pk² ∝ t_on²`, power `∝ (V·D)²/L` (ST AN1326 eq. 6/9,
  AN1262 eq. 4, US 4,862,338) → amplitude grows ~linearly with D. This is
  why "50% is the max" fails on this topology.
- The drain ring reaches its first valley exactly **one resonant half-period
  `Tv = π√(Lp·Cd)` after demagnetization** (AN1326 eq. 4). At T = 9.2 µs with
  Tv ≈ 4.6 µs, any D > ~0.5 truncates the ring — matching the current
  departing its plateau at exactly 50%.
- Clipped ring = non-ZVS turn-on: the residual drain-capacitance energy dumps
  through the FET every cycle (`P ≈ [(5/6)·Coss·ΔV^1.5 + ½·Cd·ΔV²]·f_sw`,
  AN1326) — the documented mechanism converting the superlinear input current
  into switch/inductor heat instead of mist. L1's measured heating and the
  current blow-up are also consistent with core saturation (the `∝ t_on²` law
  explicitly assumes an unsaturated core); distinguishing the two needs a
  scope on the drain (late-ramp upward curvature = saturation; turn-on spike
  = capacitive dump).

**Instability above ~75% — three documented candidate classes** (any or all):
period-doubling/chaotic dynamics in switching converters (arXiv 1210.7295);
uneven alternating cycles when quantized resonant timing fights per-cycle
energy balance (AN1326); high-intensity fountain-structure breakdown — "the
drop-chain fountain structure becomes less defined" (PMC 4428615; note that
study saw atomization still *increasing*, so the mist *decline* here is
better attributed to the clipped drive than to the fountain).

## Bottom line (unchanged, now quantified)

- **50% duty** = efficiency knee and the battery-sustainable operating point
  (~0.3 A cell current). Library default `dutyMax = 127` stands.
- **~70% duty** = true mist maximum ≈ the v2.0 "turbo" `setMaxDuty(178)`:
  ~3.5–4× the input power of 50%, wall-power territory, brief cell sprints
  only (a full cell reaches it once, riding the LDO floor).
- **>75%** = unstable, declining mist, ~10 W in, D1 at ~2× rating on stiff
  supplies. No operational value; do not park there.

## Open questions (future scope session, optional)

1. Saturation vs non-ZVS dump: scope Q4's drain at 60–75% duty.
2. Subharmonic (f_PWM/2) content on the piezo above 75% would confirm
   period-doubling; slow (seconds) drift would implicate thermal detuning.
3. A kitchen-scale water-loss measurement per duty step would turn the visual
   mist axis into numbers and pin the exponent `n`.
4. Literature value of `n` near 100 kHz remains uncited (verification
   infrastructure failed, not refuted) — re-run if it ever matters.

**Sources (part 2):** ST AN1326 (L6565 quasi-resonant, eq. 4/6/9 + capacitive
loss + uneven-cycle note); ST AN1262 (L6590, eq. 4); US Patent 4,862,338
(ringing-choke converter); arXiv 1210.7295 (period doubling in DC-DC
converters); arXiv 1609.03607 (TI DRV2700-class flyback piezo driver context);
PMC 4428615 (ultrasonic fountain structure at high intensity).

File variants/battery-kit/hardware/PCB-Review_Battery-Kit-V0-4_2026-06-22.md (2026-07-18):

# PCB Review — MistMaker Battery-Kit V0-4

**Date:** 2026-06-22  **Reviewer:** Claude Code (automated audit)  **Scope:** Full design review — BOM + every LCSC value, footprints, ERC/DRC, circuit sanity.
**Audited artifact:** on-disk saved KiCad files (note: project lock files were present, so the board may be open in KiCad — re-export if you have unsaved edits).
**Tools:** `kicad-cli` 10.0.1 (BOM/ERC/DRC/netlist export), Diode `pcb` 0.4.0 (`pcb scan` datasheet reader), LCSC product-page verification, custom footprint-geometry parser, TI/Diodes datasheets.

---

## 1. Verdict

**Fab-ready, no buildability defects.** All 37 BOM lines map to the correct LCSC part/value/package. All placed footprints are geometrically correct. No copper/connectivity errors (DRC: 0 unconnected, 0 footprint errors). The power architecture is sound and **V0.4 resolves the V0.3 USB-only false-low-battery shutdown** (mux is correctly USB-priority).

The findings below are **refinements, hygiene, and procurement** — nothing blocks a build, but several are worth fixing before a production run.

### Action items (ranked)

| # | Priority | Item |
|---|---|---|
| 1 | **Should-fix** | **C14 (10 µF 0402, 10 V — C307415)** sits on the BAT node (~4.2 V). A 10 V X5R 0402 derates heavily under DC bias (effective ≪ 10 µF). Use a 16/25 V part, or rely on C5 (0603) as the real bulk. Also lowest-stock cap (1,880). |
| 2 | **Should-fix** | **Charger thermal:** 500 mA (R6 = 2 kΩ) on the LP4060 **SOT-23-5** ≈ 1.05 W at a depleted cell (2.9 V) vs 0.5 W package rating. It self-throttles (safe) but runs hot and won't deliver full current until the cell is >~3.7 V. Consider 300–400 mA (R6 ≈ 2.5–3.3 kΩ) for a small cell, and/or more copper. |
| 3 | **Should-fix** | **U4 (UCC27511A gate driver) has no local VDD bypass** — only shared 22 µF bulk on the 5 V net. Add 0.1–1 µF directly across U4 VDD(1)–GND(4). |
| 4 | **Should-fix** | **LED3 (white) marginal:** driven from a 3.3 V GPIO through 150 Ω into a white LED with Vf ≈ 3.1 V (C51933306) → ~0.2 V headroom; dim and Vf-tolerance-sensitive. Drive from 5 V (via transistor) or accept it as a faint indicator. |
| 5 | **Confirm intent** | **J7 & J8** (a second pair of 1×07 headers) are `in_bom no` **but `dnp no`** — placed, not-DNP, yet hidden from the BOM (their sisters J1/J10 *are* in the BOM). Resolve: mark DNP if unpopulated, or add to BOM if they should be stuffed. |
| 6 | **Hygiene** | **Two footprints are misnamed** (lands are correct): `Q4` uses footprint `DMP3007SCG7` (a SOT-23 part name) but is correctly a **9-pad DFN3×3-8**; `IC2` uses `TPS62932DRLR` but is correctly an **8-pad SOT-583**. Rename to the real parts and confirm symbol pin-mapping. |
| 7 | **Hygiene** | **Broken library source paths** — custom symbol/footprint libs (`PH-2PWB`, `XEL4030-102MEC`, `Switch_DavidLib`) point at a *different* Google-Drive account (`davidyangemail@gmail.com`). Symbols are cached so the board builds, but you can't re-sync/edit. Fix `sym-lib-table`/`fp-lib-table` paths. |
| 8 | **Hygiene** | ERC error: a **dangling bus-to-wire entry** at (−105.41, 95.25). Clean up the stray wire. |
| 9 | **Procurement** | Secure before production: **U2 AP7361C (only 240 in LCSC stock)**, **L2 Coilcraft XEL4030 (Extended/special-order)**. Most parts are JLCPCB **Extended** (per-part feeder fees) — only Q1 (2N7002) is Basic. Many jellybean passives show LCSC-retail OOS but are JLC-Basic-class and typically available for assembly — verify at order time, don't panic. |
| 10 | **Optional** | Boost lands at **4.95 V** (low end of a 5.0–5.5 V intent). Raise R12 (~824 kΩ → 5.5 V) if you want margin. Optional ~220 pF feedforward cap across R12 for phase margin (COUT ≈ 44 µF). |

---

## 2. BOM + LCSC verification — all 37 lines

Every line was checked against its LCSC product page (manufacturer P/N, value, package, stock). **Result: 0 wrong parts, 0 package mismatches.** "Pkg ✓" = the schematic footprint matches the real part's package.

| Ref(s) | Value | LCSC | Real part (MPN / Mfr) | Pkg ✓ | LCSC stock | Notes |
|---|---|---|---|---|---|---|
| R1 | 30 mΩ | C7467247 | FRM121WFR030TM / FOJAN (1206, 1 W) | ✓ | 38,400 | Current-sense shunt |
| R2 | 10 Ω | C22859 | 0603WAF100JT5E / UNI-ROYAL | ✓ | OOS* | |
| R3 | 2.2 Ω | C22939 | 0603WAF220KT5E / UNI-ROYAL | ✓ | OOS* | |
| R4,R15 | 30 kΩ | C138008 | RC0402FR-0730KL / YAGEO | ✓ | OOS* | Mux PR1 top divider (R4) |
| R5 | 5.1 kΩ | C25905 | 0402WGF5101TCE / UNI-ROYAL | ✓ | OOS* | CHRG LED limit |
| R6,R7 | 2 kΩ | C4109 | 0402WGF2001TCE / UNI-ROYAL | ✓ | OOS* | **R6 = charger PROG (→500 mA)** |
| R8,R14,R16,R18,R19 | 10 kΩ | C25744 | 0402WGF1002TCE / UNI-ROYAL | ✓ | OOS* | R8 = boost EN pull-up; R16 = mux PR1 bottom |
| R9 | 150 Ω | C25082 | 0402WGF1500TCE / UNI-ROYAL | ✓ | OOS* | LED3 series |
| R10 | 1 kΩ | C106235 | RC0402FR-071KL / YAGEO | ✓ | OOS* | |
| R11,R17 | 100 kΩ | C14675 | RC0603FR-07100KL / YAGEO | ✓ | 100 | R11 = Q4 gate pulldown |
| R12 | 732 kΩ | C137940 | RC0402FR-07732KL / YAGEO | ✓ | OOS* | **Boost FB top** |
| R13,R21 | 100 kΩ | C25741 | 0402WGF1003TCE / UNI-ROYAL | ✓ | OOS* | **R13 = boost FB bottom** |
| R20 | 22 Ω | C25092 | 0402WGF220JTCE / UNI-ROYAL | ✓ | OOS* | Series gate resistor |
| R22 | 150 kΩ | C25755 | 0402WGF1503TCE / UNI-ROYAL | ✓ | OOS* | |
| C1 | 0.1 µF | C14663 | CC0603KRX7R9BB104 / YAGEO (50 V X7R) | ✓ | OOS* | LDO out bypass |
| C5,C6,C12,C15,C16 | 10 µF | C96446 | CL10A106MA8NRNC / Samsung (0603, **25 V** X5R) | ✓ | 195,780 | Bulk — comfortable rating |
| C7,C8,C9 | 22 µF | C98190 | CL21A226MOQNNNE / Samsung (0805, 16 V X5R) | ✓ | 79,500 | Boost in/out bulk |
| C10 | 1 µF | C14445 | CL05A105KP5NNNC / Samsung (0402, 10 V) | ✓ | 29,200 | |
| C13,C14 | 10 µF | C307415 | CL05A106MP8NUB8 / Samsung (0402, **10 V** X5R) | ✓ | 1,880 | ⚠ **10 V at BAT node — see action #1** |
| D1 | PMEG10010ELRX-TP | C7603319 | PMEG10010ELRX / Nexperia (SOD-123FL, 100 V 1 A Schottky) | ✓ | 46,440 (Ext) | Flyback clamp |
| Q1 | 2N7002 | C8545 | 2N7002 / JSCJ (SOT-23, 60 V N-MOSFET) | ✓ | OOS* (JLC **Basic**, 466 k) | |
| Q4 | DMT10H009LCG-7 | C461105 | DMT10H009LCG-7 / Diodes (**VDFN3333-8**, 100 V 47 A) | ✓ (footprint **misnamed**) | 313 (Ext) | Land is correct 9-pad DFN; rename footprint |
| IC1 | TPS61023 | C919459 | TPS61023DRLR / TI (SOT-563 boost) | ✓ | 34,120 (Ext) | |
| IC2 | TPS2116DRLR | C3235557 | TPS2116DRLR / TI (**SOT-583** mux) | ✓ (footprint **misnamed**) | 17,303 (Ext) | Symbol confirmed TPS2116; rename footprint |
| J1,J10 | Conn 1×07 socket | C27985232 | 1×7 2.54 mm female socket | ✓ | 6,512 | |
| J2,J3 | PH-2PWB | C2905019 | PH-2PWB / DEALON (2-pin 2 mm conn) | ✓ | 20,140 | |
| J6 | Qwiic | C2845372 | JST-SH-compat 1×04 1.0 mm | ✓ | 10,350 | Check gender vs mating cable |
| L1 | 3-Legged Inductor | C49338546 | XRCD75-250K/801K / XR (dual-winding 25 µH/800 µH) | ✓ | 6,160 | Verify 3-leg pinout vs datasheet |
| L2 | XEL4030-102MEC | C5441341 | XEL4030-102MEC / Coilcraft (1 µH, 9 A) | ✓ | not shown | **TI-recommended boost inductor**; likely Extended |
| LED1 | Green | C965793 | XL-1005UGC / XINGLIGHT (0402) | ✓ | 852,450 | Charge-status indicator |
| LED2 | Red | C25503345 | XL-1005SURC / XINGLIGHT (0402) | ✓ | 628,900 | 5 V-present indicator |
| LED3 | White | C51933306 | GL0402UW01 / Guiguang (0402, Vf 3.1 V) | ✓ | 144,950 | ⚠ Vf headroom — see action #4 |
| S2 | TS-1088-AR02016 | C720477 | TS-1088-AR02016 / XUNPU (SMD tactile) | ✓ | 754,070 | |
| U1 | LP4060B5F | C517259 | LP4060B5F / LOWPOWER (SOT-23-5, Li-ion charger) | ✓ | 910 (Ext) | 4.2 V float |
| U2 | AP7361C-3.3V | C151007 | AP7361C-33FGE-7 / Diodes (DFN-8 3×3, 3.3 V 1 A LDO) | ✓ | **240** (Ext) | Lowest stock — secure early |
| U3 | INA180A3 | C122882 | INA180A3IDBVR / TI (SOT-23-5, gain 100) | ✓ | 48,355 (Ext) | |
| U4 | UCC27511ADBV | C2676982 | UCC27511ADBVR / TI (SOT-23-6 gate driver) | ✓ | 13,340 | |

\* **OOS = out of stock on LCSC *retail*.** These are jellybean 1 % chip resistors / a basic cap — almost all are JLCPCB **Basic** parts that remain available for *assembly* even when LCSC retail shows zero. Verify against JLCPCB's assembly inventory at order time; not a BOM defect.

---

## 3. Footprint audit (geometry-verified from the PCB)

Every placed footprint was parsed from the `.kicad_pcb` and classified by pad count + pitch, then compared to the real part's package. **All lands are physically correct.** Two are misnamed:

| Ref | Footprint name in board | Actual geometry | Real part package | Status |
|---|---|---|---|---|
| Q4 | `DavidLib_Switch:DMP3007SCG7` | 9 pads, 0.65 mm pitch, ~2×3 mm | DMT10H009 = VDFN3333-8 | ✓ correct land, **wrong name** (DMP3007 is SOT-23) |
| IC2 | `DavidLib_Mux:TPS62932DRLR` | 8 pads, 0.50 mm pitch, ~1.5×1.5 mm | TPS2116DRLR = SOT-583 | ✓ correct land, **wrong name** (TPS62932 is a buck) |

All other ICs/passives/connectors verified correct (U1 SOT-23-5, U2 DFN-8 3×3, U3 SOT-23-5, U4 SOT-23-6, IC1 SOT-563, Q1 SOT-23, D1 SOD-123FL, L1 3-leg, J-sockets, etc.).
The `kibuzzard-*` "footprints" are silkscreen-art labels (0 pads) — correctly excluded from the BOM.

> **Why naming matters:** KiCad fabricates whatever pads are in the board file — it never cross-checks them against the package the LCSC code ships in. The lands here are right, but a footprint named after a *different* part is a real maintenance hazard (future edits may trust the name). Rename to the actual part.

---

## 4. ERC / DRC

**DRC: 10 violations — all `lib_footprint_mismatch (Local override)`** (J7, D1, C10, R10, R22, J8, LED3, Q1, S2, Q4). These mean the placed footprint was locally edited vs its library copy — benign for a self-contained board, but a symptom of the library drift in action #7. **0 unconnected pads, 0 footprint errors.**

**ERC: 22 (4 errors, 18 warnings).** Nothing structural:
- *Errors:* dangling bus-to-wire entry (action #8); TP1 pin-not-connected (test point — expected); IC1 VIN & H1 "power pin not driven" (missing PWR_FLAG annotation — the netlist confirms IC1 VIN is fed by PSW_VOUT, so this is cosmetic).
- *Warnings:* LP4060 (U1) pins typed "Unspecified" → `pin_to_pin` warnings (symbol hygiene — set proper pin types); several `multiple_net_names` aliases (`XIAOVIN`=`MODE`, `5V5_MIST`=`L_LEG1`, `L_LEG2`=`PIEZO+`, `L_LEG3`=`PIEZO-`, `BATT-`=`2N7002_S`) — mostly intentional labels on the autotransformer legs, but confirm none is an accidental merge; broken-library warnings (action #7).

---

## 5. Design review (circuit sanity)

**Rail chain:** USB/battery → LP4060 charger → BATT+; **TPS2116 mux** (VIN1=USB, VIN2=BATT+) → PSW_VOUT → feeds **both** the TPS61023 boost (→ ~4.95 V) **and** the AP7361C LDO (→ 3.3 V). Boost/LDO run from the mux output (battery-or-USB), not from the boosted rail — intentional and correct.

| Subsystem | Finding | Severity |
|---|---|---|
| **Charger (U1 LP4060)** | R6 = 2 kΩ → I_BAT = 1000/R = **500 mA**, 4.2 V float. Correct for Li-Po. But PD ≈ 1.05 W at VBAT 2.9 V vs 0.5 W SOT-23-5 rating → self-throttles, runs hot. | OK / **WARN (thermal)** |
| **BAT decoupling** | C14 (10 µF 0402 **10 V**) + C5 (10 µF 0603 25 V). C14 derates hard at 4.2 V. | **WARN** |
| **Power mux (IC2 TPS2116)** | MODE=VIN1 → priority mode; PR1 = R4 30 k / R16 10 k → VIN1 threshold 4.0 V. USB @5 V → PR1 = 1.25 V > VREF → **USB selected & passed through**. **Resolves the V0.3 false-low-batt shutdown.** | **OK ✓** |
| **Boost (IC1 TPS61023)** | FB R12 732 k / R13 100 k, VREF 0.595 V → **Vout = 4.95 V** (low end of 5–5.5 V). L2 = 1 µH (exact TI-recommended). CIN 42 µF / COUT 44 µF in range. No feedforward cap (optional). | OK / NOTE |
| **LDO (U2 AP7361C-3.3)** | Fixed 3.3 V, EP grounded, CIN 42 µF / COUT 10 µF+0.1 µF. Dropout ~0.34 V @1 A → tight on a near-empty battery, fine on USB. | OK / NOTE |
| **Current sense (U3 INA180A3)** | High-side, gain 100, 30 mΩ → **3.0 V/A**; Vs ≈ 4.95 V → max measurable **~1.6 A**; shunt 0.075 W (1206) fine. | OK / NOTE (range) |
| **Gate drive (U4 → Q4)** | OUTH→R2(10 Ω) / OUTL→R3(2.2 Ω) → R20(22 Ω) → Q4 gate; R11 100 k pulldown. R_on 32 Ω / R_off 24.2 Ω. R20 shared swamps the driver's 4 A/8 A asymmetry. **No local VDD cap.** Q4 100 V hugely over-rated for the ~5 V-rail flyback. D1 a proper clamp. | OK / **WARN (decap)** |
| **LEDs** | LED1 green = charge-status (~0.5 mA, dim, cosmetic); LED2 red = 5 V-present (~1.5 mA, OK); **LED3 white ~0.2 V headroom (3.1 V Vf on 3.3 V GPIO)**. | OK / **WARN (LED3)** |

---

## 6. Cross-board consistency (vs Seeed Extension V0.1)

Shared parts use the **same LCSC code on both boards** — good: INA180A3 (C122882), UCC27511A (C2676982), DMT10H009 (C461105), PH-2PWB (C2905019), 30 mΩ shunt (C7467247), PMEG10010 (C7603319), 3-leg inductor (C49338546).
One behavioral difference to confirm intentional: the **INA180 runs off ~5 V here (range ~1.6 A) but off 3.3 V on the Extension board (range ~1.1 A)**.

---

## 7. Caveats

- LCSC "stock" is retail and time-sensitive; JLCPCB *assembly* stock differs (see note under §2).
- LED Vf and exact derated capacitance values are nominal/datasheet — confirm on hardware for the marginal items (LED3, C14).
- The audit reflects the **saved** files; if the board is open in KiCad with unsaved changes, re-run the export.
- Raw exports (BOM CSVs, ERC/DRC reports, netlists, datasheet markdowns) are in the audit scratch dir and can be regenerated with `kicad-cli` 10.0.1.

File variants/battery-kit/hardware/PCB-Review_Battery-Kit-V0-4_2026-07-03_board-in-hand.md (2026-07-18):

# PCB Review — MistMaker Battery-Kit V0-4 (board-in-hand)

**Date:** 2026-07-03  **Reviewer:** Claude Code (Fable)  **Scope:** As-built verification of the received V0.4 boards + component-by-component wiring review with emphasis on the new **TPS2116 ST → XIAO D8** power-source sense, post-order design drift, JLC part re-check, and status of the 2026-06-22 action items.
**Method:** `kicad-cli` 10.0.1 netlist/ERC/DRC on local copies; netlist-level diff between the **ordered** design (backup `2026-06-22_162548`, matching `production/` fab outputs) and the **current** saved files (edited 2026-06-24 and 2026-07-01); TI TPS2116 datasheet (`pcb scan`) for ST/MODE/PR1 semantics. Companion doc: `PCB-Review_Battery-Kit-V0-4_2026-06-22.md` (full 37-line LCSC verification — still valid, BOM unchanged except R6/R7 noted below).

---

## 1. Verdict

**The board you received is safe to bring up.** DRC on the ordered layout: 10 benign footprint-name warnings, 0 connectivity errors (same as the June audit). Netlist connectivity of the current schematic is **identical** to what was fabbed — no wiring changed after the order. The ST→D8 subsystem is correctly designed and datasheet-verified: **D8 HIGH = USB, LOW = battery**, matching library v1.2.0 semantics.

### What changed after the order (design drift)

| Item | Ordered (= your physical board) | Current sch (Jul 1) | Meaning |
|---|---|---|---|
| **R6** (LP4060 PROG) | 5.1 kΩ (C25905) → **~196 mA charge** | same | Fixed *before* order — June action #2 (charger thermal) is RESOLVED on your board |
| **R7** (LED2 series) | **2 kΩ** (C4109) → LED2 ~1.5 mA | **5.1 kΩ** (C25905) | Post-order cosmetic dimming; your board has the brighter red LED |
| PCB copper / constraints | — | unchanged (early DRC scare was a missing `.kicad_dru` in the test copy, not a design change) | — |

---

## 2. ST → D8 power-source sense (the V0.4 headline) — VERIFIED ✓

**Chain:** IC2 pin 8 (ST, open-drain) —[R15 30 k pull-up to XIAOVIN]— node `/ST` (also Q1 gate, TP3) —[R21 100 k]— node `D8_ST` (J10.6 = XIAO D8) —[R22 150 k]— GND.

- **Datasheet (TPS2116 §7.3.3):** ST pulled **low when VIN1 (USB) is not in use** — i.e., released when USB powers the output. With the pull-up: ST high on USB, low on battery.
- **USB present:** XIAOVIN ≈ 5 V → D8 = 5 × 150k/(30k+100k+150k) ≈ **2.68 V = HIGH**. On battery: ST asserted low *and* the pull-up rail itself is dead → **0 V = LOW, doubly guaranteed**, with zero battery drain through the network (I_ST leak 0.03 µA).
- **MODE** tied to VIN1 → priority mode ✓. **PR1** divider R4/R16 = 30k/10k, V_REF = 1.0 V → USB selected above **4.0 V** ✓.
- **Q1 (2N7002) side-effect — document this:** ST high (USB) turns Q1 on, pulling **U2 (AP7361C LDO) EN low → board LDO OFF on USB**; the XIAO then runs from its own onboard regulator. On battery, Q1 releases and R17 (100 k → PSW_VOUT) enables the LDO. Elegant: the two 3.3 V regulators never fight.
- **Firmware rule (already in v1.2.0 bring-up):** D8 must be `INPUT` with **no internal pull** — a ~45 k internal pull-up to 3.3 V would put the battery-state node at an indeterminate ~1.9 V.

### ⚠ Thin margin (works, fix in V0.5)
On USB, D8 ≈ 2.68 V vs ESP32-C6 V_IH ≈ 0.75 × 3.3 = **2.48 V — only ~0.2 V margin**, less if the XIAO 5 V pin sits below 5.0 V. Bench-verified working (2026-07-02), but for V0.5 retune, e.g. **R22 150 k → 220 k** → D8 ≈ 3.14 V @ 5 V in (still < 3.3 V abs-max at 5.25 V VBUS: 3.30 V).

### Break-before-make caution (bring-up test)
Switchover disconnects both inputs for ~1.3 ms. USB unplug while running = mux output dip + LDO restart via Q1/R17. Buffered by C6/C12/C7 (42 µF) + C15/C1 on 3V3. **Bring-up must include a live-unplug/replug test** to confirm no MCU reset.

---

## 3. Component-by-component review (current files ≡ as-built except R7)

| Subsystem | Parts | Finding |
|---|---|---|
| **Charger** | U1 LP4060B5F, R6 5.1 k (PROG), LED1 grn + R5 5.1 k (CHRG, open-drain) | ✓ ~196 mA — thermally comfortable for SOT-23-5 (June's 500 mA concern fixed). Charger VCC on XIAOVIN → unpowered (no drain) on battery. |
| **Power mux** | IC2 TPS2116, R4/R16 (PR1), R15/R21/R22 (ST), Q1+R17 (LDO gate) | ✓ Verified above. Footprint land = correct SOT-583 (name still says `TPS62932DRLR` — hygiene). |
| **LDO** | U2 AP7361C-3.3, C15 10 µF + C1 0.1 µF out, EP grounded | ✓. Dropout ~0.34 V @ 1 A → 3V3 sags on a near-empty cell (< ~3.64 V) — inherent, acceptable. |
| **Boost** | IC1 TPS61023, L2 XEL4030-102, R12/R13 FB (→ 4.95 V), R8 10 k EN pull-up to PSW_VOUT, CIN C6/C12/C7 = 42 µF, COUT C8/C9 = 44 µF | ✓. **Note: EN pulled HIGH → the ~5 V mist rail is live from power-on** before any firmware runs (piezo stays off because U4 input idles low through the XIAO's boot-time high-Z + gate pulldowns — see gate drive). Firmware should still drive D3 explicitly. |
| **Gate drive** | U4 UCC27511A (VDD on 5 V), OUTH R2 10 Ω / OUTL R3 2.2 Ω → R20 22 Ω → Q4 gate, R11 100 k pulldown | ✓ wiring. **Still no local 0.1–1 µF at U4 VDD** (June #3, open) — nearest bulk is C8/C9. Works, but add in V0.5 for clean 108.7 kHz edges. |
| **Mist tank** | 5 V → R1 30 mΩ → D1 PMEG10010 (series) → L1 3-leg autotransformer; Q4 switches leg 2; piezo across legs 2–3 (J3); leg breakouts J12/J13 | ✓ single-transistor resonant drive; D1 blocks resonant kickback into the boost. Q4 (100 V) generously rated for the flyback ring. |
| **Current sense** | R1 → U3 INA180A3 (V+ = 3V3, inputs on 5 V rail) → R10 1 k + C10 1 µF RC → D2 | ✓. Full-scale ~1.1 A (3.3 V/3.0 V-per-A); RC gives ~160 Hz smoothing — matches library averaging. |
| **Battery ADC** | R18/R19 10 k/10 k, BATT+ → D1_BATT_VOLTAGE | ✓ ratio 2.0 = library default. **Two design notes:** (a) divider is hard-wired → **~210 µA constant drain** (≈ 5 mAh/day; dominates deep-sleep budgets — fine for this product's duty cycle, but a V0.5 candidate: high-side switch or ST-gated divider); (b) **no filter cap on the ADC tap** — readings ride on mist-load sag; library's 16-sample averaging + hysteresis compensates. |
| **Button** | S2, COM → 3V3, NO → D6 + R14 10 k pulldown | ✓ **active-HIGH** (pressed = 3.3 V). Bring-up/library docs must match. |
| **LEDs** | LED1 grn (charge), LED2 red (5 V rail via JP5V5, R7), LED3 wht (D7 GPIO, R9 150 Ω, J11 jumper) | LED1/2 ✓. **LED3 still marginal** (June #4, open): 3.1 V V_f on a 3.3 V GPIO → expect *dim*; treat as faint indicator or fix in V0.5 (drive from 5 V via Q1-style transistor). |
| **Connectors** | J1/J10 XIAO socket; J7/J8 mirror pads (not stuffed, excluded from BOM, `dnp no` — June #5 still open as hygiene); J2 battery, J3 piezo (PH-2PWB); J6 Qwiic (3V3/GND/D4/D5) ✓; TP2 PR1, TP3 ST, TP4 gate, TP6 PSW_VOUT; J4/J5/J9/J11–J15 single-pin breakouts | ✓ Pin map confirmed: **D0 mist-PWM, D1 batt-ADC, D2 current-sense, D3 boost-EN, D4/D5 I²C, D6 button, D7 LED3, D8 ST** — exactly `MistMakerBatteryKitV04()`. |

**ERC:** 24 warnings/errors — same profile as June (dangling bus entry at (−105.41, 95.25) still present = June #8 open; TP1 no-connect; PWR_FLAG cosmetics; LP4060 unspecified pin types). Nothing structural.

---

## 4. June 22 action items — scorecard

| # | Item | Status on your physical board |
|---|---|---|
| 1 | C14 10 µF **10 V** 0402 on BAT node (C307415) | **OPEN** — ordered as-is. Derates hard at 4.2 V; C5 (25 V 0603) is the real bulk. Harmless for bring-up; use 16/25 V part in V0.5. |
| 2 | Charger thermal (500 mA) | **FIXED before order** — R6 = 5.1 k → ~196 mA. |
| 3 | U4 local VDD bypass | **OPEN** — no new cap in ordered or current files. V0.5. |
| 4 | LED3 white headroom | **OPEN** — unchanged. Expect dim. V0.5. |
| 5 | J7/J8 BOM/DNP hygiene | **OPEN** (cosmetic) — unstuffed on the build, so no physical issue. |
| 6 | Footprint renames (Q4 `DMP3007SCG7`, IC2 `TPS62932DRLR`) | **OPEN** (hygiene) — lands verified correct; rename to real packages. |
| 7 | Library-table paths → wrong Drive account | **OPEN** — `sym-lib-table`/`fp-lib-table` still reference the personal-account paths; migrate to the kicad-libraries repo nicknames. |
| 8 | Dangling bus-to-wire ERC | **OPEN** — still at (−105.41, 95.25). |
| 9 | Procurement (U2 stock 240, U1 910, L2 extended) | **STANDING** — re-check before the next run. |
| 10 | Boost 4.95 V → raise to 5.5 V option | **NOT TAKEN** — fine as-is; revisit only if mist output underwhelms. |

## 5. JLC parts check

BOM is the June-verified 37-line set (all LCSC numbers confirmed correct then; **no part-number changes since**) with two value moves inside already-verified parts: R6 → C25905 (5.1 k, shared with R5) on the build; R7 → C25905 in the current sch (build has C4109 2 k). The bulk-cap error that briefly existed in the repo's V0.3 BOM (**C25804** = a 10 kΩ resistor!) is **not** in the V0.4 order — C96446 (10 µF 25 V) was correctly ordered. Ordered CPL/BOM (`production/bom.csv`, `positions.csv`, 2026-06-22 16:25) match the ordered schematic exactly.

## 6. Recommended V0.5 delta (collected)

1. R22 150 k → 220 k (D8 HIGH margin).
1b. **R8: boost-EN pull-up → pull-DOWN.** During ESP32 deep sleep the D3 GPIO
   releases and R8 (10 k → PSW_VOUT) re-enables the boost, so "graceful
   low-battery deep-sleep" still leaks ~0.3–0.5 mA through the idle 5 V rail.
   Default-off EN (pull-down to GND) fixes the drain *and* the rail-live-at-boot
   quirk; D3 (GPIO21) isn't an RTC GPIO on the C6, so firmware gpio-hold isn't a
   reliable substitute. (From the 2026-07-02 firmware review.)
2. 0.1–1 µF at U4 VDD pins 1–4.
3. C13/C14 → 16/25 V 10 µF (or drop C14, keep C5).
4. LED3: transistor drive from 5 V (or accept faint).
5. Battery divider: gate with a P-FET or size up (drain ~210 µA); add 100 nF at the ADC tap.
6. Hygiene: rename Q4/IC2 footprints, DNP-mark J7/J8, delete dangling bus entry, fix lib-table paths, set LP4060 symbol pin types.
7. Port the R7 = 5.1 k LED2 change into the next fab (already in current sch).

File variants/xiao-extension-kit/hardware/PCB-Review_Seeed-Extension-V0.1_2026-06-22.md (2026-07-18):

# PCB Review — MistMaker Seeed (XIAO) Extension V0.1

**Date:** 2026-06-22  **Reviewer:** Claude Code (automated audit)  **Scope:** Full design review — BOM + every LCSC value, footprints, ERC/DRC, circuit sanity.
**Audited artifact:** on-disk saved KiCad files.
**Tools:** `kicad-cli` 10.0.1 (BOM/ERC/DRC/netlist export), Diode `pcb` 0.4.0 (`pcb scan` datasheet reader), LCSC product-page verification, custom footprint-geometry parser, TI/Diodes/Nexperia datasheets.
**What it is:** a Seeed XIAO (ESP32-C6) carrier that drives a piezo mist atomizer via a low-side MOSFET + autotransformer, with high-side current sense and a Qwiic I²C port.

---

## 1. Verdict

**Fab-ready, no buildability defects.** All 17 BOM lines map to the correct LCSC part/value/package; all placed footprints are geometrically correct; DRC shows 0 unconnected pads / 0 footprint errors. The findings are refinements and intent-confirmations.

### Action items (ranked)

| # | Priority | Item |
|---|---|---|
| 1 | **Should-fix** | **U3 (UCC27511A gate driver) is missing its bulk VDD cap.** Only a single 0.1 µF (C5) on VDD/5 V; the datasheet calls for **0.1 µF + ~1 µF** for an 8 A-sink driver. Add a ~1 µF low-ESR cap right at U3 VDD(1)–GND(4). Matters more here because VDD = 5 V is only ~0.8 V above the driver's UVLO. |
| 2 | **Confirm** | **VBUS must stay ≥ ~4.7 V under mist load.** The driver runs at 5 V (XIAO VBUS) with only ~0.8 V of UVLO margin; a sagging USB source could drop it into UVLO and kill the gate drive. Verify on the bench. |
| 3 | **Confirm** | **Current sense saturates at ~1.09 A.** INA180A3 (gain 100) runs off **3.3 V** with the 30 mΩ shunt → 3.0 V/A, clipping at ~1.09 A. Confirm the atomizer's peak current is below that; if not, run the INA off 5 V or use the gain-50 INA180A2. |
| 4 | **Confirm intent** | **U1 (XIAO 2×7 header) and J1 (Qwiic) are `dnp yes` + `in_bom no`** — deliberately excluded. Correct *if* the XIAO is soldered directly (footprint is `XIAO-Add-On_No_Edge`, castellated) and the Qwiic port is intentionally unpopulated. If you wanted a removable socket and/or a live I²C port, those parts are **not currently on the order** — clear their DNP/BOM flags. |
| 5 | **Confirm (firmware)** | **The mist PWM is on GPIO0**, an ESP32-C6 **strapping pin**. A transient high at boot could briefly pulse the atomizer (driver is non-inverting). Drive GPIO0 low early in firmware, or move PWM off GPIO0 in a respin. |
| 6 | **Confirm** | **No on-board I²C pull-ups** (SDA/SCL only reach the XIAO and the Qwiic connector). Fine *iff* the Qwiic peripheral provides them (SparkFun Qwiic boards do). If you ever add an on-board I²C device, fit 4.7 kΩ pull-ups. |
| 7 | **Hygiene** | **Footprint Q3 is misnamed** `DMP3007SCG7` (a SOT-23 part) but is correctly a **9-pad DFN3×3-8** for the DMT10H009. Rename + confirm symbol pin-mapping. |
| 8 | **Hygiene** | **Broken library source paths** — `Mist_Custom` points at a stale `MistMakerV1-8` folder; `PH-2PWB` lib not in config. Symbols are cached so the board builds, but fix `sym-lib-table` to re-enable editing. Also a **net-label typo: `MOSFET_DRIAN`** (→ `MOSFET_DRAIN`). |
| 9 | **Verify (topology)** | **"5V5_MIST" is not a regulated 5.5 V boost** — it's an autotransformer/flyback piezo driver (D1 is a clamp/steering diode, not a boost rectifier). Confirm the PWM frequency matches the atomizer's resonance, and scope Q3's drain to confirm the ring stays < 100 V. Consider an RC snubber pad on Q3 drain (none present). |

---

## 2. BOM + LCSC verification — all 17 lines

Every line checked against its LCSC product page. **Result: 0 wrong parts, 0 package mismatches.**

| Ref | Value | LCSC | Real part (MPN / Mfr) | Pkg ✓ | LCSC stock | Notes |
|---|---|---|---|---|---|---|
| C1 | 0.1 µF | C14663 | CC0603KRX7R9BB104 / YAGEO (50 V X7R) | ✓ | OOS* | |
| C2 | 1 µF | C14445 | CL05A105KP5NNNC / Samsung (0402, 10 V) | ✓ | 29,200 | CS RC-filter cap |
| C5 | 100 nF | C3011705 | GRM188R72A104KA35J / muRata (0603, 100 V X7R) | ✓ | 4,320 | U3 VDD bypass (see action #1) |
| D1 | PMEG10010ELRX-TP | C7603319 | PMEG10010ELRX / Nexperia (SOD-123FL, 100 V 1 A) | ✓ | 46,440 (Ext) | Flyback clamp |
| J3 | PH-2PWB | C2905019 | PH-2PWB / DEALON (2-pin 2 mm conn) | ✓ | 20,140 | Piezo output |
| L1 | 3-Legged Inductor | C49338546 | XRCD75-250K/801K / XR (dual-winding 25 µH/800 µH) | ✓ | 6,160 | Autotransformer; verify 3-leg pinout |
| LED2 | Red | C25503345 | XL-1005SURC / XINGLIGHT (0402) | ✓ | 628,900 | Status indicator |
| Q3 | DMT10H009LCG-7 | C461105 | DMT10H009LCG-7 / Diodes (**VDFN3333-8**, 100 V 47 A) | ✓ (footprint **misnamed**) | 313 (Ext) | Land is correct 9-pad DFN |
| R1 | 30 mΩ | C7467247 | FRM121WFR030TM / FOJAN (1206, 1 W) | ✓ | 38,400 | Current-sense shunt |
| R2 | 10 Ω | C22859 | 0603WAF100JT5E / UNI-ROYAL | ✓ | OOS* | Gate **turn-on** R (OUTH) |
| R3 | 2.2 Ω | C22939 | 0603WAF220KT5E / UNI-ROYAL | ✓ | OOS* | Gate **turn-off** R (OUTL) |
| R4 | 100 kΩ | C14675 | RC0603FR-07100KL / YAGEO | ✓ | 100 | Q3 gate pulldown |
| R5 | 1 kΩ | C106235 | RC0402FR-071KL / YAGEO | ✓ | OOS* | CS RC filter (with C2) |
| R7 | 510 Ω | C25123 | 0402WGF5100TCE / UNI-ROYAL | ✓ | OOS* | Driver input/enable network |
| R20 | 22 Ω | C25092 | 0402WGF220JTCE / UNI-ROYAL | ✓ | OOS* | Series gate resistor |
| U2 | INA180A3 | C122882 | INA180A3IDBVR / TI (SOT-23-5, gain 100) | ✓ | 48,355 (Ext) | Runs off 3.3 V → ~1.09 A range |
| U3 | UCC27511ADBV | C2676982 | UCC27511ADBVR / TI (SOT-23-6 gate driver) | ✓ | 13,340 | |

**Not in BOM but on the PCB (intentionally excluded — confirm per action #4):** `U1` XIAO 2×7 header (`in_bom no`, `dnp yes`), `J1` Qwiic JST-SH (`in_bom no`, `dnp yes`), `JP5V5` solder jumper, `LOGO1` silkscreen graphic.

\* **OOS = LCSC *retail* out of stock** — jellybean 1 % chips / basic caps that are JLCPCB **Basic**-class and typically available for *assembly*. Verify at order time; not a defect.

---

## 3. Footprint audit (geometry-verified from the PCB)

All placed lands are physically correct. One misnamed:

| Ref | Footprint name in board | Actual geometry | Real part package | Status |
|---|---|---|---|---|
| Q3 | `DavidLib_Switch:DMP3007SCG7` | 9 pads, 0.65 mm pitch, ~2×3 mm | DMT10H009 = VDFN3333-8 | ✓ correct land, **wrong name** |

All others verified (U2 SOT-23-5, U3 SOT-23-6, D1 SOD-123FL, J3 PH2PWB connector, L1 3-leg, U1 XIAO 2×7 header, passives sized right). `kibuzzard-*` = silkscreen art (0 pads), correctly not in BOM.

---

## 4. ERC / DRC

**DRC: 4 violations — all `lib_footprint_mismatch (Local override)`** (J3, Q3, LED2, L1) = library drift, benign. **0 unconnected pads, 0 footprint errors.**

**ERC: 16 (10 errors, 6 warnings)** — nothing structural:
- *Errors:* 7× `pin_not_connected` on the XIAO header's unused GPIOs (expected — not every XIAO pin is used); U2 V+ / IN+ "power pin not driven" (missing PWR_FLAG annotation — INA is on XIAO3V3); LOGO1 graphic pin.
- *Warnings:* `PH-2PWB` lib not in config + `Mist_Custom` stale path (action #8); `multiple_net_names` aliases on the autotransformer legs (`5V5_MIST`=`L_LEG1`, `L_LEG3`=`PIEZO-`, `L_LEG2`=`MOSFET_DRIAN`) — mostly intentional, but note the **`MOSFET_DRIAN` typo**; SolderJumper symbol mismatch.

---

## 5. Design review (circuit sanity)

| Subsystem | Finding | Severity |
|---|---|---|
| **Mist driver (D1, L1, Q3)** | 5 V → R1 shunt → D1 → L1 center-tap; L1 outer legs → Q3 drain + piezo (J3); Q3 source → GND. This is an **autotransformer/flyback piezo driver PWM'd by the XIAO via U3**, *not* a regulated 5.5 V boost — D1 is a clamp, not a rectifier. No output/snubber cap on the switch node. | NOTE — verify resonance & drain ring < 100 V |
| **Gate drive (U3 → Q3)** | OUTH→R2(10 Ω) turn-on / OUTL→R3(2.2 Ω) turn-off → R20(22 Ω) → Q3 gate; R4 100 k pulldown. R_on 32 Ω / R_off 24.2 Ω — split-output used correctly. **Only 0.1 µF on VDD** (wants 0.1 µF + 1 µF). VDD 5 V ≈ 0.8 V over UVLO. | **WARN (decap)** + NOTE (UVLO) |
| **Current sense (U2 INA180A3)** | High-side 30 mΩ shunt, gain 100 → **3.0 V/A**; **Vs = 3.3 V → clips at ~1.09 A**; CS lands on XIAO A2 (ADC-capable ✓), RC-filtered (R5 1 k + C2 1 µF). | NOTE (range) |
| **I²C** | SDA/SCL reach only the XIAO + Qwiic J1 — **no on-board pull-ups**. OK iff the Qwiic peripheral supplies them. | NOTE |
| **XIAO interface (U1)** | PWM = GPIO0 (**strapping pin** — guard at boot), CS = GPIO2/A2 (ADC ✓), SDA/SCL on header pins 5/6, VBUS pin14, 3V3 pin12, GND pin13. Mapping is sane. | NOTE (GPIO0) |
| **Q3 / D1 ratings** | Q3 100 V DMT10H009 and D1 100 V PMEG10010 — both 100 V, consistent with an expected high autotransformer ring. Fully enhanced at 5 V VDD. | OK |

---

## 6. Cross-board consistency (vs Battery-Kit V0.4)

Shared parts use the **same LCSC code on both boards** (INA180A3 C122882, UCC27511A C2676982, DMT10H009 C461105, PH-2PWB C2905019, 30 mΩ C7467247, PMEG10010 C7603319, 3-leg inductor C49338546) — good.
**One difference to confirm intentional:** the INA180 current-sense runs off **3.3 V here (range ~1.09 A)** vs **~5 V on the Battery board (range ~1.6 A)**. If both boards must measure the same atomizer current, the lower ceiling here is the binding limit.

---

## 7. Caveats

- LCSC "stock" is retail/time-sensitive; JLCPCB *assembly* stock differs (see §2 note).
- The mist-driver topology interpretation is from netlist tracing + datasheets; confirm against your reference atomizer-driver design and on the bench (drain ring, resonance).
- Current/headroom figures use nominal Vf/derating; verify the marginal items on hardware.
- Audit reflects the **saved** files; re-export if there are unsaved KiCad edits.

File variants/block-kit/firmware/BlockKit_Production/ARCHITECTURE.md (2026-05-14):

# Block Kit V0.1 — Production Firmware at a Glance

One-page technical overview. For install + bring-up steps see [`README.md`](README.md).

## Stack

| Layer | Choice |
|---|---|
| MCU | Seeed XIAO ESP32-C6 (RISC-V, 160 MHz, 512 KB SRAM, 4 MB flash) |
| Toolchain | Arduino IDE 2.x + `esp32` core v3.3+ |
| Sketch layout | Multi-`.ino` (Arduino auto-concatenates) — no `.cpp`/`.h` pairs |
| External lib | [`Dav1dyang/Adafruit_IS31FL3731`](https://github.com/Dav1dyang/Adafruit_IS31FL3731) fork (Matrix B addressing) |
| State, allocation | One state machine, all `static` module-private state, **no heap, no `String`** |
| Math style | Integer + LUTs (no `sinf()` — ESP32-C6 has no FPU) |
| Boards supported | XIAO_ESP32C6 (production), XIAO_ESP32S3 (port), QT Py ESP32 family (compile-only) |

## Hardware (3 PCBs)

| PCB | Role |
|---|---|
| **Driver** | XIAO socket, USB-C + LP4068BF charger, TPS2116 mux, AP7361C 3V3 LDO, TPS61023 3V3→5V boost, UCC27518 level shifter, DMT10H009 MOSFET → piezo, INA180A3 + 30 mΩ shunt |
| **Mist & LED** | IS31FL3731 (14 LEDs on Matrix B / CB1+CB2), reed switch, piezo connector, Qwiic |
| **Button** | Single B3AL-1002P tactile on WAGO-2059 |

Mist drive: 108.7 kHz / 0–50 % PWM into a piezo disc. Container has a magnet that closes the reed when docked.

## Pin Map (XIAO ESP32-C6)

| Net | Pin | GPIO | Direction | Notes |
|---|---|---|---|---|
| `PIN_MIST_PWM` | D0 | 0 | OUT (LEDC) | 108.7 kHz, duty 0..127 |
| `PIN_CURRENT_ADC` | D2 | 2 | ADC1_CH2 | INA180A3 via 1 kΩ + 1 µF LPF |
| `PIN_BOOST_EN` | D3 | 21 | OUT | TPS61023 EN (HIGH = 5 V rail on); side-effect: red LED2 lights |
| `PIN_BUTTON` | D6 | 16 | IN_PULLDOWN | Active-HIGH; PCB 10 kΩ pull-down |
| `PIN_STATUS_LED` | D7 | 17 | OUT (LEDC) | White LED, dim "waiting" indicator |
| `PIN_REED` | D10 | 18 | IN_PULLUP | LOW = magnet present; **V0.1 blue-wire rework** |
| SDA / SCL | D4 / D5 | 22 / 23 | I2C | IS31FL3731 (0x74) + Qwiic |

`D0..D10` come from the XIAO platform header directly. Non-XIAO boards (QT Py) get explicit per-variant `PIN_*` defs guarded by `ARDUINO_xxx` macros; unknown boards `#error`.

## State Machine

```
                     ┌────────────────────────────┐
                     │ IDLE (boot, LEDs visible)  │
                     │ strip = BREATH             │
                     │ deep-dim exp(sin) pulse;   │
                     │ exhale lingers at black    │
                     │ mist off                   │
                     └────┬───────────────────────┘
                          │ container docked (500 ms dwell)
                          ▼ (BREATH→WAVE crossfade, 1.1 s)
                 ┌─────────────────────────────────────────────┐
                 │ RUNNING                                     │
                 │   strip = WAVE: every LED always lit,       │
                 │   single broad gaussian swell traveling     │
                 │   bottom→top over 7.5 s (slow, meditative). │
                 │   mist on, modulated by the swell at the    │
                 │   piezo position (1 LED above index 0)      │
                 │   D7 off                                    │
                 └─────┬───────────────────────────────────────┘
                       │ container removed
                       ▼
                 ┌─────────────────────────────────────────────┐
                 │ TRANSITION_FROM_RUNNING                     │
                 │   mist hard-stopped                         │
                 │   wave still rendering, dims to 0 (~0.85 s) │
                 │   auto-enters IDLE →                        │
                 │   WAVE→BREATH crossfade (1.1 s) +           │
                 │   fast level restore (~0.64 s)              │
                 └─────┬───────────────────────────────────────┘
                       │ smoother reaches 0
                       ▼
                      IDLE

  Orthogonal short-press LED hide flag (any state):
     g_ledsHidden=false  ─── short-press ──►  g_ledsHidden=true
     LEDs visible (~640 ms fade)              LEDs dark, mist untouched
```

Short-press toggles `g_ledsHidden` in any state — the LED render fades to/from 0
over ~640 ms, but mist behavior is unaffected (so the diffuser keeps running at
the user-set level even while the visuals are blanked). Re-docking during
`TRANSITION_FROM_RUNNING` cleanly re-enters `RUNNING` (the crossfade engine
handles any mode swap mid-fade — no special case needed).

| From → To | Trigger | Effect |
|---|---|---|
| IDLE → RUNNING | reed Inserted (500 ms dwell) | mist on (wave-modulated), mode = WAVE → 1.1 s BREATH→WAVE crossfade in pre-gamma space |
| RUNNING → TRANSITION_FROM_RUNNING | reed Removed (100 ms dwell) | **mist hard-stop**; mode stays WAVE, baseLevel ramps 255→0 (~0.85 s) — wave dims naturally |
| TRANSITION_FROM_RUNNING → IDLE | smoother lands on 0 | mode→BREATH (kicks off WAVE→BREATH crossfade), fast fade-up to `g_userLevel` (~0.64 s) |
| TRANSITION_FROM_RUNNING → RUNNING | reed re-Inserted mid-fade | crossfade engine handles WAVE→WAVE no-op; mist re-armed |
| any state | button short-press | toggles `g_ledsHidden` (LED render fades to/from 0; mist + state untouched) |
| IDLE / RUNNING | button long-press | ramps `g_userLevel`; mist + LED brightness scale live (wave traverse rate stays constant) |

## Level Model (the trick)

One scalar drives both mist and LEDs so they always move together. A separate, orthogonal scaler hides the LED strip without touching the mist.

```
g_userLevel    (0..255)   ← user's intent; long-press ramps this
g_targetLevel  (0..255)   ← state-driven goal (0 in
                            TRANSITION_FROM_RUNNING, g_userLevel otherwise)
g_currentLevel (0..255)   ← smoothed actual; ramps toward target +2 / 10 ms
                            (≈ 1.3 s 0→255). Step size is intentionally tiny
                            so the slide reads as continuous, not stepped —
                            the prior +3/+4 stepping was the "snappy" feel.
                            Post-removal breath restore uses STEP_UP_FAST
                            (~0.64 s) so the cinematic stays brisk.

g_ledsHidden   (bool)     ← short-press toggle; orthogonal to state
g_ledScale     (0..255)   ← smoothed visibility scaler; eases toward
                            g_ledScaleTarget = (g_ledsHidden ? 0 : 255)
                            over ~640 ms (step 4 / 10 ms). Multiplies the
                            baseLevel handed to ledRender; mist ignores it.

mist duty   = (mistOutLevel(g_currentLevel, now) × MIST_DUTY_MAX) / 255
              where mistOutLevel(level, now) applies the wave-sync
              factor:
                factor (Q8) = MIST_WAVE_TROUGH_Q8
                            + ((256 - MIST_WAVE_TROUGH_Q8) × gauss_at_piezo) >> 8
                gauss_at_piezo = waveIntensityAtPiezo(now)  // 0..255
              In any state other than RUNNING, mist is inhibited (boost
              rail down) so the value is don't-care.
LED bright  = led_driver((g_currentLevel × g_ledScale) >> 8, g_ledMode)
              where led_driver:
                BREATH:  exp(sin) curve LUT, capped to LED_BREATH_PEAK (raw
                         80 → PWM 10/255 ≈ 4 %) so idle stays dim regardless
                         of baseLevel; all 14 LEDs share brightness;
                         baseLevel scales the whole.
                WAVE:    every LED at WAVE_BASE_LEVEL, plus gaussian swell
                         (σ=4 LEDs, 64-entry LUT, linear-interp) traveling
                         bottom→top over WAVE_PERIOD_MS. baseLevel scales
                         the whole render uniformly.
              Mode swaps (ledSetMode) auto-trigger a 1.1 s pre-gamma
              crossfade between the previous and current mode.
```

Pieces sitting outside the smoother:
- **Reed lift** → `mistHardStop()` cuts boost rail + PWM immediately and sets an inhibit flag so the still-fading `g_currentLevel` can't re-engage the boost. `enterRunning()` clears the inhibit.
- **Wave-mist sync** → in `RUNNING`, mist drive is *additionally* modulated by `waveIntensityAtPiezo(now)`, which samples the wave's gaussian 1 LED above the top of the strip (where the piezo sits). Same `now` is fed to the visible WAVE renderer, so the mist crest you feel is the wave crest you see, delayed only by the geometry of the piezo sitting above the top LED.
- **Short-press LED hide** → toggles `g_ledsHidden`. `g_ledScale` smooths in/out over ~640 ms and multiplies the baseLevel handed to `ledRender`. Mist drive does not pass through this scaler, so blanking the visuals never stops the diffuser.
- **D7** is driven once per loop from `containerIsPresent()` — independent of `state`, `level`, and `g_ledsHidden`.
- **led_driver crossfade engine** — `ledSetMode()` captures the prior mode and starts a `LED_CROSSFADE_MS` timer. While elapsed < timer, both modes render every frame and outputs are linearly blended per LED in pre-gamma space. Replaces the prior `g_pendingSwirl` state-machine flag — the BREATH↔WAVE swap is now a single continuous dissolve, not "fade up then snap".

## User Interactions

| User does | Result |
|---|---|
| Power on | Boots to `IDLE` with LEDs visible — strip starts a deep-dim exp(sin) breath; the exhale dwells at full black for a beat each cycle |
| Dock container | ~500 ms reed dwell → mist on (wave-modulated at the piezo); mode flips to WAVE, the dim breath dissolves into the slow gaussian swell over 1.1 s (single continuous crossfade). Mist visibly pulses in sync with the LED swell. |
| Lift container | Mist hard-stops instantly. Wave dims to black over ~0.85 s (mode stays WAVE so it reads as continuous), then the dim breath crossfades back in over 1.1 s |
| Tap button (any state) | Toggles `g_ledsHidden` — LED strip fades to dark (or back in) over ~640 ms. **Mist is not affected** — if a container is docked, the diffuser keeps running at the user-set level even while the strip is hidden |
| Hold button (IDLE or RUNNING) | Ramps `g_userLevel` — brightness scales live and mist drive scales with it (still wave-modulated in RUNNING). Wave traverse rate stays constant. Direction alternates on release. The ramp clamps at 0 / 255 — there is no auto-snap-to-off; long-pressing to 0 just leaves the device at level 0 (mist off, LEDs dark), and the next long-press in the opposite direction brings it back. |

## Files

| File | Role |
|---|---|
| `BlockKit_Production.ino` | state machine, smoother, LED-visibility smoother, wave-mist sync (`mistOutLevel`), serial parser, glue |
| `pins.h` | pin defs, tunables, enums — single source of truth |
| `mist.ino` | `mistApply(level)`, `mistHardStop`, boost rail gating, inhibit |
| `led_driver.ino` | `ledRender(baseLevel)` — renders BREATH (exp(sin) LUT, linear-interp, capped to LED_BREATH_PEAK) or WAVE (gaussian-LUT swell traveling bottom→top), 1.1 s pre-gamma crossfade between modes, gamma + per-LED I2C write cache. Also exposes `waveIntensityAtPiezo(now)` so the main loop can phase-lock mist drive to the wave swell. |
| `status_led.ino` | D7 dim-on / off |
| `container.ino` | reed debounce, edge events |
| `button.ino` | debounce, short/long-press events |
| `current_sense.ino` | INA180 ADC @ 1 kHz, rolling mean+variance, scope mode |

Arduino concatenates all `.ino` files into one translation unit, so file-scope `static` only scopes per file by convention — names use module prefixes (`g_longPressTickMs`, `g_ledLastRenderMs`, …) to avoid collisions.

## Serial Commands (115200 baud)

| Cmd | Effect |
|---|---|
| `help` | print list |
| `l` / `L` / `t` | hide LEDs / show LEDs / toggle visibility (mist untouched) |
| `vN` | set `g_userLevel` 0..255 |
| `w` | LED walk (sequence 14 LEDs, ~14 s, blocks) |
| `r` | dump reed state (raw + debounced) |
| `s` | toggle scope mode (raw current samples @ 100 Hz) |
| `m` | mute / unmute periodic `[PLOT]` |
| `k` | (Phase B placeholder) recalibrate baseline |

Log line prefixes: `[APP]`, `[MIST]`, `[LED]`, `[REED]`, `[BTN]`, `[CUR]`, `[STAT]`, `[PLOT]`, `[CMD]`.

## Key Tuning Constants (`pins.h`)

| Constant | Value | Why |
|---|---|---|
| `MIST_FREQ_HZ` | 108 700 | Piezo disc resonance |
| `MIST_DUTY_MAX` | 127 | 50 % of 8-bit PWM = full mist |
| `MIST_PIEZO_OFFSET_LEDS_Q8` | 256 | Piezo position above index 0 (1 LED) for the wave-mist sync gauss sample |
| `MIST_WAVE_TROUGH_Q8` | 92 | Mist trough factor (92/256 ≈ 36 %) — matches `WAVE_BASE_LEVEL` / 255 so the mist's swing mirrors the LED's |
| `LEVEL_DEFAULT` | 255 | First-boot mist + brightness |
| `LEVEL_SMOOTH_TICK_MS` / `STEP_UP` / `STEP_DN` | 10 / 2 / 3 | ~1.3 s fade-in, ~0.85 s fade-out — tiny steps so the slide reads as continuous |
| `LEVEL_SMOOTH_STEP_UP_FAST` | 4 | ~0.64 s breath restore after removal — keeps the cinematic brisk |
| `LED_SCALE_STEP_PER_TICK` | 4 | ~0.64 s short-press LED hide/show fade |
| `LED_BREATH_PEAK` | 80 | raw cap on breath sweep → PWM 10/255 ≈ 4 % post-gamma. Picked so the sweep covers ~10 distinct PWM levels (smooth gradient) instead of the 1 level peak=38 gave (blink-like). |
| `LED_BREATH_PERIOD_MS` | 5500 | One slow inhale → exhale → black-dwell |
| `WAVE_BASE_LEVEL` | 92 | Always-on baseline every LED holds (docked) |
| `WAVE_SWELL_PEAK` | 163 | base + peak = 255 at swell crest |
| `WAVE_PERIOD_MS` | 7500 | One swell traverses the strip — slow, meditative |
| `WAVE_SIGMA_LEDS_Q8` | 1024 | σ = 4 LEDs — broad, soft gaussian (no hard edges) |
| `LED_CROSSFADE_MS` | 1100 | BREATH ↔ WAVE pre-gamma crossfade window |
| `LED_TICK_MS` | 20 | 50 fps render |
| `REED_INSERT_DWELL_MS` / `REMOVE_DWELL_MS` | 500 / 100 | Asymmetric: slow on, fast off |
| `BUTTON_LONGPRESS_MS` / `LONGTICK_MS` | 500 / 13 | ~77 steps/sec while held |
| `STATUS_LED_DIM_DUTY` | 24 / 255 | ~10 % brightness — visible, not bright |

## What's NOT in Phase A

- Water-level classifier (variance-based LOW_WATER detection). Bench-validation data is collected via scope mode (`s`); Phase B PR adds the classifier.
- NVS persistence of `g_userLevel`. Reset every boot.
- Battery monitoring. Requires V0.2 hardware (VBAT divider).
- Watchdog (`esp_task_wdt`). Deferred so debugger pauses don't reset.

## WiFi onboarding + OTA + Web config (production firmware additions)

Three new modules sit on top of the existing UX state machine. All ride
on libraries bundled with arduino-esp32 v3.x — the only external
install is **WiFiManager** (tzapu).

### `config.ino` — runtime config
Every UX tunable that used to be `constexpr` in `pins.h` is now a field
on a `Config cfg` struct backed by NVS (`Preferences`, namespace
`blockkit`, key `cfg_v1`). `pins.h` keeps each value as a
`CFG_DEFAULT_*` constant — those seed `cfg` at boot if NVS is empty or
a `CONFIG_VERSION` mismatch is detected. Secrets (admin password
SHA-256 hash, OTA password, hostname) are stored as separate NVS keys
so a config schema bump doesn't drop the user's password.

### `wifi_setup.ino` — WiFiManager captive portal
`autoConnect("BlockKit-Setup-XXXX", "blockkit-setup")` either joins
saved STA credentials or spins up a WPA2 AP + captive portal. A
custom parameter prompts for the admin password during first-boot
setup; it's hashed and stored. mDNS is announced as `<hostname>.local`
(default `blockkit`).

### `ota.ino` — ArduinoOTA
`onStart` calls `mistHardStop()` + drives D3 (boost EN) LOW + blanks
the LED ring *before* flash erase begins, so an aborted upload leaves
the MOSFET gate in a known-LOW state. Password is the admin password.

### `web_server.ino` + `web_ui.h` — single-page web UI
Synchronous `WebServer.h` on port 80; one PROGMEM HTML/CSS/JS blob
(~12 KB) served at `/`. Routes:

| Verb + path | Auth | Returns |
|---|---|---|
| `GET /` | none | INDEX_HTML |
| `GET /api/status` | none | live status JSON |
| `GET /api/config` | none | `cfg` snapshot (no secrets) |
| `POST /api/config` | admin pwd | apply + save one field |
| `GET /api/info` | none | device info (mac/ip/ver/heap) |
| `GET /api/log` | none | last N log lines (plain text) |
| `GET /api/events` | none | SSE stream, status every 250 ms  |
| `POST /api/cmd/walk` | admin pwd | run ledWalk on next loop |
| `POST /api/cmd/leds` | admin pwd | toggle hide/show LEDs |
| `POST /api/cmd/scope`  | admin pwd | toggle scope mode |
| `POST /api/cmd/reboot` | admin pwd | restart after 250 ms |
| `POST /api/cmd/forget` | admin pwd | wipe WiFi + reboot into portal |
| `POST /api/cmd/password` | admin pwd | change admin/OTA password |

Auth: HTTP Basic against SHA-256 of the submitted password. Reads are
open; writes + commands require the password. The web UI caches the
password in `sessionStorage` per browser session.

### `log_buffer.ino` — RAM ring of Serial output
`logPrintln` / `logPrintf` mirror to both Serial and a 100-line ring
buffer; `/api/log` returns the buffer as plain text. The pre-existing
high-volume `[PLOT]` stream stays on Serial only.

### Main loop order
`otaHandle()` + `webHandle()` + `wifiTick()` run at the *top* of every
loop so an over-the-air recovery push lands even if a downstream
subsystem (LED driver, smoother) misbehaves.

## Transition cinematic (post-PR-#6 polish)

`enterIdle()` no longer sets `g_fastLevelUp = true` when called from
TRANSITION_FROM_RUNNING. The breath restore uses the slow smoother
step (~1.3 s 0→255) instead of the original brisk (~640 ms) restore.
Combined with the 1.1 s WAVE→BREATH crossfade, the post-removal
sequence reads as a gentle dim-down and a soft breath swell instead
of the previous quick flash that occurred when the breath's exp(sin)
phase landed near its inhale peak as baseLevel ramped up fast.

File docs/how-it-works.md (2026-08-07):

# How It Works

Every board in this project is the same idea with different power plumbing: an ESP32
shakes a piezo disc at its resonant frequency until water turns into mist. The
interesting part is *how* a 5 V USB rail ends up swinging tens of volts across a
ceramic disc — and why one strange little inductor makes it all work.

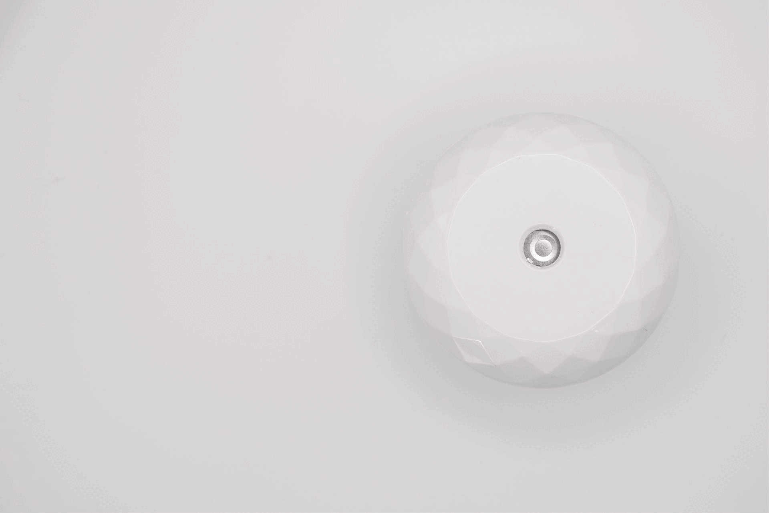
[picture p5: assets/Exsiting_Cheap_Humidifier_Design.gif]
How a cheap humidifier works


## The disc: atomization at 108.7 kHz

The mist disc isn't just a vibrating plate — it's a **micro-perforated atomizer**. The
center of the disc has microscopic holes; a cotton stick feeds water to the back side,
and as the piezo ceramic flexes at **108.7 kHz** (its mechanical resonance), each
oscillation pumps water through those holes, ejecting droplets fine enough to float as
a cool mist. No heat involved — the "steam" is room-temperature water.

This is why disc orientation matters (white ring faces up — mist exits there), why a
dirty or dry disc stops misting, and why running a disc dry can overheat it. Disc
behavior, droplet formation, and hole geometry are beautifully illustrated in the
[MDPI ultrasonic atomization study](https://www.mdpi.com/2076-3417/11/18/8350) that
informed this design.

## The resonant drive: 5 V in, ~80 Vpp out

A piezo disc is electrically a capacitor, and it wants far more voltage than a USB
port offers. Commercial humidifiers solve this with a clever resonant circuit, which
these boards adapt:

```
5V ──► gate driver ──► MOSFET ──► 3-leg tapped inductor ──► piezo disc (108.7 kHz)
        ▲ PWM from ESP32              (autotransformer + LC resonance)
5V current ──► 30 mΩ shunt ──► INA180A3 ──► ADC pin
```

1. The ESP32 outputs a **108.7 kHz PWM** (33% duty by default) into a gate driver + MOSFET.
2. The MOSFET rapidly switches the tapped inductor in a loop with the disc's own
   capacitance, forming an **LC tank** that rings at the drive frequency.
3. The inductor is *tapped* — three legs, roughly a **28 µH : 800 µH** winding ratio —
   so it doubles as an **autotransformer**, stepping the ringing voltage up to the
   ~80 Vpp the disc needs (measured on the Legacy V1.4 circuit — the production V0.x boards use the same drive topology).
4. Mist strength tracks how well the drive frequency matches the disc + inductor
   resonance — which is exactly why `setLevel()` (PWM duty) modulates mist like a
   dimmer.

    !!! info "Why the default is well under the maximum (measured 2026-07)"
        Longer on-time stores more energy in the inductor, but the resonant
        "ring-back" needs about half of each 9.2 µs cycle to swing — so past 50%
        duty the ring gets clipped and efficiency collapses. A full 0→90% duty
        sweep on V0.4 hardware found mist output actually **peaks near 70% duty**
        at ~4× the input power of the 50% point, then declines and turns unstable.
        The library defaults to a **33% cap** — bench-tested as a good amount of
        mist with the tapped inductor staying cool on long runs — and exposes the
        measured peak as `DUTY_TURBO`. Both are one call away; see the
        [library page](library.md#how-hard-can-it-drive-measured).
5. As a bonus, the current flowing through a 30 mΩ shunt (read by an INA180A3,
   3.0 V/A) differs measurably between *no disc*, *dry disc*, and *disc in water* —
   one ADC pin gives disc detection and a water sensor for free.

Stability details matter at these frequencies: the boards add RC snubbers, TVS
protection, and careful gate drive (the V0.x boards upgraded from a bare GPIO-driven
AO3400A to a dedicated UCC27511 gate driver for clean edges).

## The part you can't buy at DigiKey

The 3-legged tapped inductor is the soul of this circuit — and the hardest part to
source in the West. It doesn't meaningfully exist on DigiKey, Mouser, or Amazon, but
it's abundant and cheap on Taobao and AliExpress (search **“三腳電感”** — "three-leg
inductor"). It's a workhorse of Shenzhen-ecosystem designs: the same component that
makes commercial humidifiers compact is used to make **piezo buzzers in fire and smoke
alarms painfully loud** — same trick, voltage step-up by autotransformer + resonance
([good StackExchange teardown of exactly this part](https://electronics.stackexchange.com/questions/539843/how-does-the-component-alarm-boost-three-pin-inductor-make-a-piezo-buzzer-loud)).

The Battery Kit board seen straight on; the tapped inductor is the round shielded can at the center of the board

*What it looks like in place: the round shielded can at the center of the Battery Kit,
a turn of copper just visible at its edge — the one part on these boards you can't
order from a Western distributor.*

!!! tip "Can't get the tapped inductor?"
    Misting works without it. A standard **680 µH inductor** in series with the disc
    forms an LC resonator with the piezo's built-in capacitance; drive it at
    ~113 kHz (changes based on the disc), add a 100 nF DC-blocking capacitor, power it up with ~30VDC and you get effective (if less
    efficient) mist. We verified this alternative experimentally — it trades the
    hard-to-source part for a slightly larger, simpler circuit.

## Design evolution

PCB design progress

The project started by reverse-engineering cheap commercial humidifier circuits
(see [BigClive's teardown](https://www.youtube.com/watch?v=_TXlhOsPJyo) and [GreatScott's explainer](https://www.youtube.com/watch?v=OOZi3QnnDCo)), then rebuilding them as documented, hackable boards. The full design story is on [Hackster](https://www.hackster.io/dav1dyang/waste-into-wonder-making-programmable-mist-makers-fe3ae7).

**What we learned the hard way — and fixed in the current boards.** The Legacy V1.4 workshop board had classic quirks: serial connection inconsistent on battery, and uploads failing while misting. The Batt Kit V0.x boards design these problems away — the [Battery Kit](boards/battery-kit.md)'s **TPS2116 power mux** cleanly separates USB and battery paths (so programming just works, battery connected or not) and the piezo rail has its own dedicated boost converter. If you're reproducing the original board, the old fixes are preserved on the [Legacy V1.4 page](boards/legacy-v1-4.md#known-quirks-fixes).

## Use and care

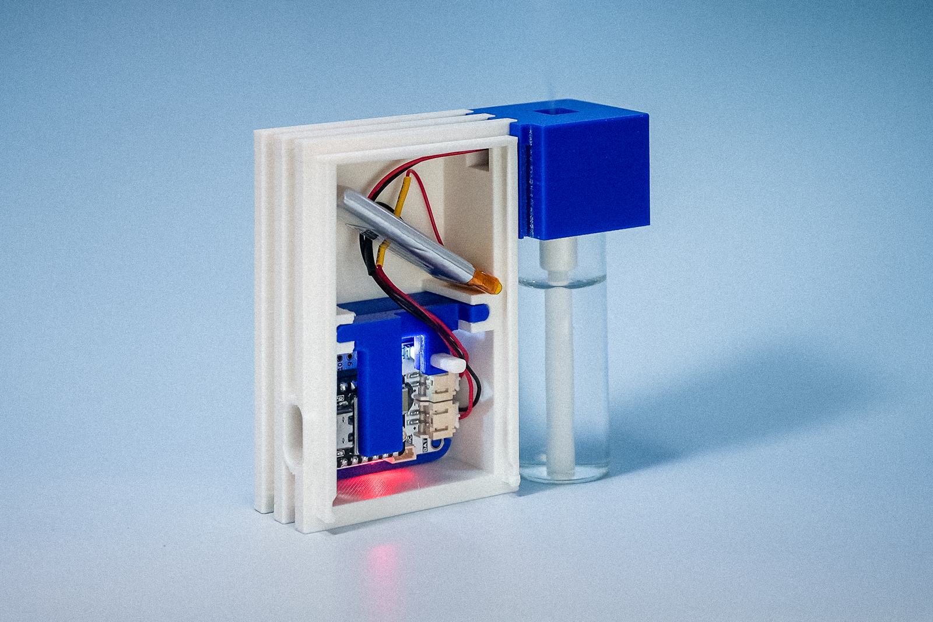
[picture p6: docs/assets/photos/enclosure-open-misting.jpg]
An open enclosure, status LED lit: the board and Li-Po cell sit in the printed frame while a cotton stick stands in a glass vial of water beside them


*The arrangement every build repeats: electronics in the dry half, water in its own
vessel, and a cotton stick as the only thing that crosses between them.*

!!! warning
    Because the device uses a water reservoir and cotton sticks to move water near
    electronics, careless operation can lead to bacterial growth over time. Use
    distilled or clean tap water, clean the container regularly, and let cotton
    sticks dry fully between uses. Keep electronics dry where they should be dry.

- Never run the disc without water for long (it can overheat), and never drive the
  circuit without a disc attached (the MOSFET can overheat).
- Mist strength varies with water depth, disc cleanliness, and supply voltage.

## Research & references

The reading list that shaped this design — also linked throughout the
[original research notes](https://dav1dyang.notion.site/programmable-mist-maker):

**Science & circuit**

- [Ultrasonic atomization study (MDPI Applied Sciences)](https://www.mdpi.com/2076-3417/11/18/8350) — disc microstructure and droplet formation
- [Tapped "alarm boost" inductor explained (Electronics StackExchange)](https://electronics.stackexchange.com/questions/539843/how-does-the-component-alarm-boost-three-pin-inductor-make-a-piezo-buzzer-loud)
- [Mist maker circuit walkthrough (EDN)](https://www.edn.com/mist-maker/)

**Teardowns & tutorials**

- [GreatScott! — How ultrasonic humidifiers work](https://www.youtube.com/watch?v=OOZi3QnnDCo)
- [BigCliveDotCom — commercial mist maker teardown](https://www.youtube.com/watch?v=_TXlhOsPJyo)
- [Nick Electronics — how a humidifier works](https://www.youtube.com/watch?v=bngLvPxtoLA)

**Datasheets**

- [TPS61023 boost converter (TI)](https://www.ti.com/lit/ds/symlink/tps61023.pdf)
- [AO3400A MOSFET](https://mm.digikey.com/Volume0/opasdata/d220001/medias/docus/2587/UMW%20AO3400A.pdf) (legacy V1.4 switch; V0.x uses DMT10H009LCG + UCC27511)

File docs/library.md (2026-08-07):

# MistMaker Library

**[MistMaker](https://github.com/owochel/MistMaker)** is the Arduino library for every
board in this project — PWM mist control, current sensing, battery monitoring, and
power-source awareness behind one friendly API. Treat mist like an LED.

## Install

Arduino IDE → **Library Manager** → search "MistMaker", or clone
[owochel/MistMaker](https://github.com/owochel/MistMaker) into your libraries folder.

Minimum version depends on your board: **v2.1+** for the
[Battery Kit](boards/battery-kit.md) and [Legacy V1.4](boards/legacy-v1-4.md),
**v2.2+** for the [Extension Kit](boards/extension-kit.md), **v2.5+** to drive a kit
from an [Arduino over jumper wires](labs/making-mist-with-an-arduino.md). Newest is
always safe.

!!! warning "v2.6 changed how hard the boards drive by default"
    The default duty cap dropped from 127 (50%) to **85 (33%)** — bench-tested as a
    good amount of mist with the tapped inductor staying cool on long runs. Because
    [`setLevel()` is a ratio of the cap](#how-hard-can-it-drive-measured), **every
    level now drives ~33% less than on v2.5.x**, not just the top end. To get the
    old output back, set the cap explicitly: `mist.setMaxDuty(127);`

Every tuning value the library assumes lives in one documented place:
`namespace MistMakerDefaults` at the top of `MistMaker.h`.

## Quick start

```cpp
#include <MistMaker.h>

// One line per board — pick yours:
MistMaker mist(MistMakerBatteryKitV041());  // current production board (V0.4: same preset)
// MistMaker mist(MistMakerBatteryKitV04());  // identical pins — either name works
// MistMaker mist(MistMakerBatteryKitV03()); // V0.3: battery sensing off by default
// MistMaker mist(MistMakerExtensionV01());
// MistMaker mist(MistMakerBlockKitV01());
// MistMaker mist(MistMakerLegacyV1());

void setup() {
  mist.begin();
  mist.turnOn();        // full mist
  mist.setLevel(128);   // half mist — dim it like an LED
}

void loop() {}
```

Custom wiring? Use the pin constructor: `MistMaker mist(mistPin, enPin, sensePin, ledPin);`
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

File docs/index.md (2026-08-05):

# Programmable Mist Maker

**A simple open source, battery powered & programmable IoT mist making device** — by
[shuang cai](https://shuangcai.cargo.site/) and [David Yang](https://davidyang.work/)
at ByProduct Lab.

A Battery Kit board with a XIAO ESP32-C6 and a Li-Po cell, driving a piezo disc that is actively misting

*The whole device: a XIAO ESP32-C6, one board, a 1S Li-Po, and a piezo disc — misting
with nothing else attached.*

This [Open Source Hardware Certified](https://certification.oshwa.org/us002742.html)
project (OSHWA **US002742**) turns a piezo disc, a custom PCB, and any small container
into a programmable mist device. Most mist circuits online lack documentation — this
project fills that gap with tested reference circuits, full KiCad sources, an Arduino
library, and honest notes about what went wrong along the way.

First presented as a hands-on workshop at the **Open Hardware Summit 2025**.
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

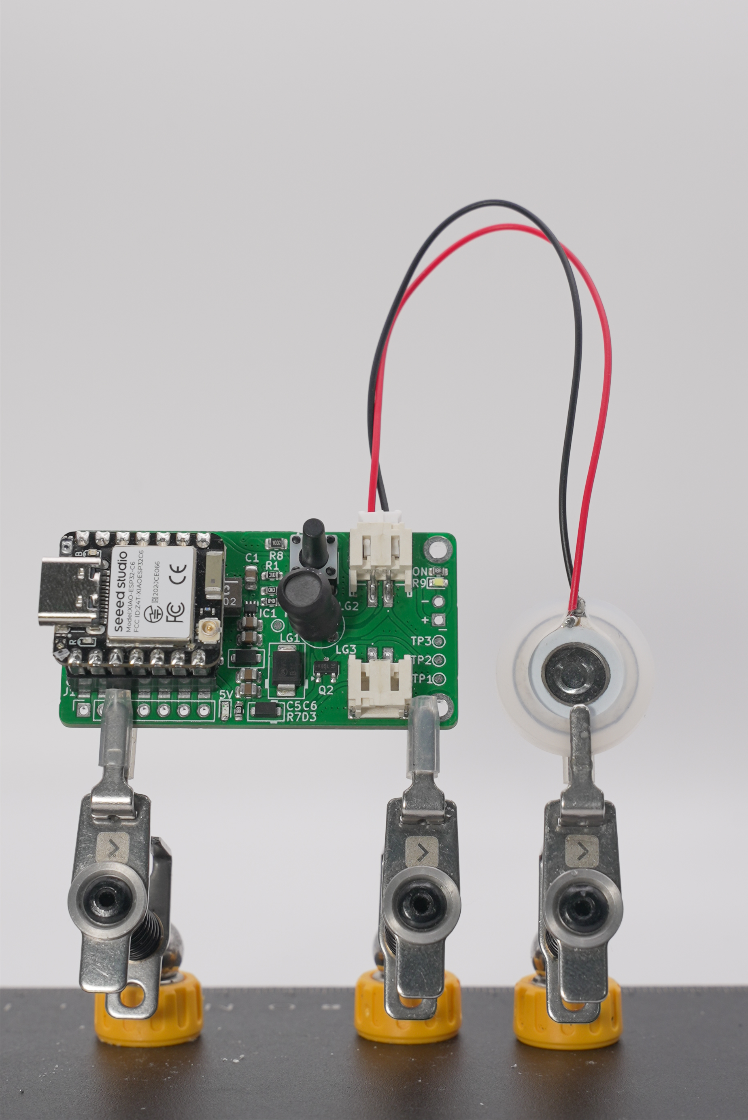
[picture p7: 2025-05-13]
assets/V1-2_PCB_Baord_Design.jpg

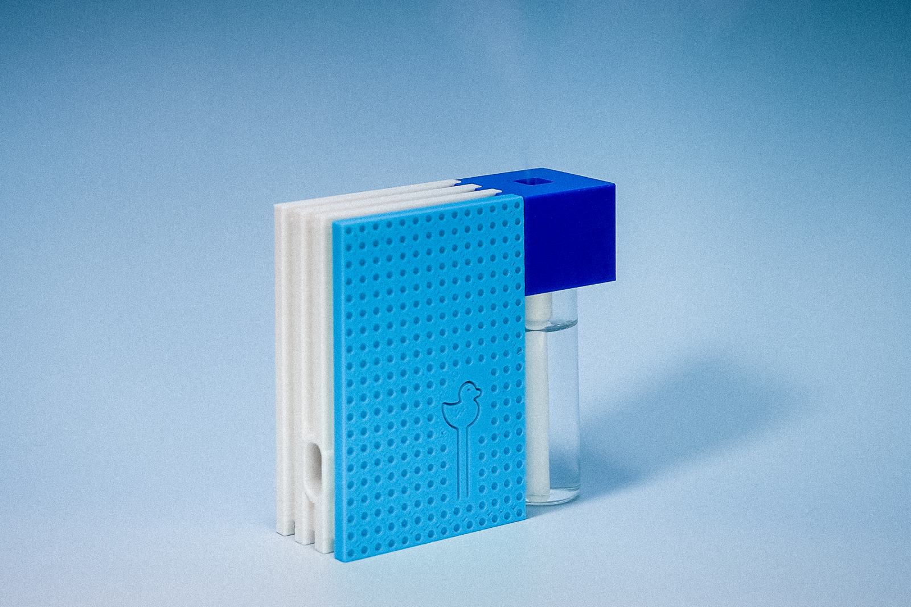
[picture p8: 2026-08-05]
docs/assets/photos/enclosure-finished.jpg

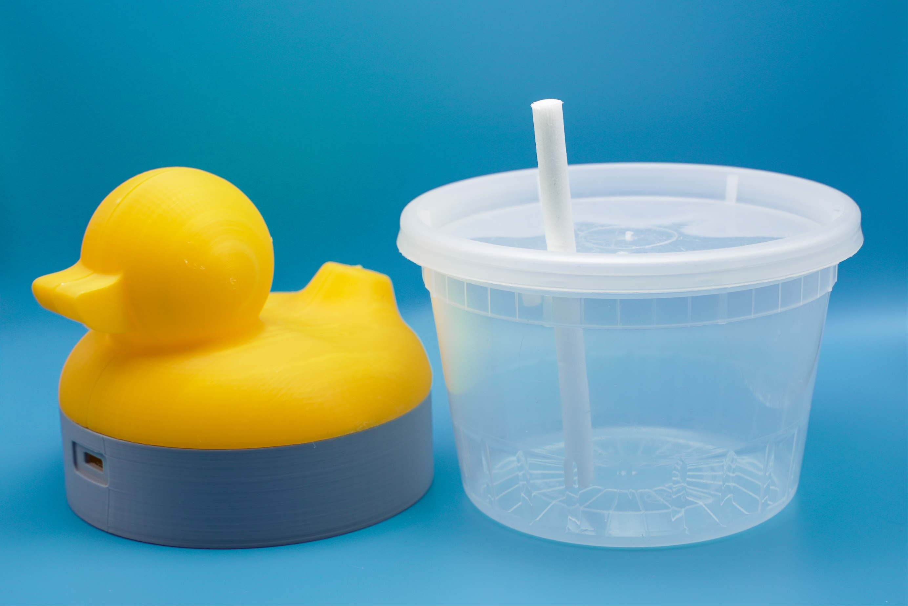
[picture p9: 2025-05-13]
assets/Ducky_and_Container.jpg

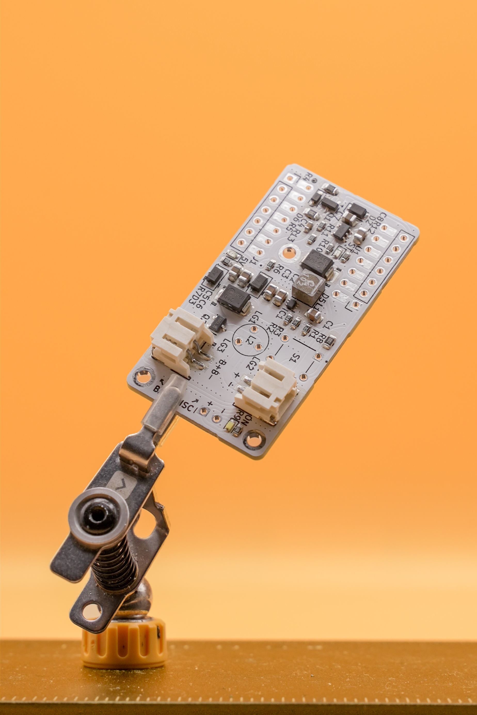
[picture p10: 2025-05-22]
assets/2025-05-22_V1-4_Board_Only.jpg

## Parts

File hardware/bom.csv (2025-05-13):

Designator | Footprint | Quantity | Value | LCSC Part #
C1, C2, C3 | 0805 | 3 | 22uF | C98190
C4 | 0603 | 1 | 100nF | C3011705
C5, C6, C7, C8 | 0805 | 4 | 10uF | C326595
D2 | D_SOD-123F | 1 | MBR120 | C81143
D3, D4 | D_SOD-123F | 2 | SMF6.0A | C19077499
D5, D7 | D_SMB_Min_Silk | 2 | MBRS1100 | C82068
D6 | D_SOD-323_HandSoldering | 1 | D_TVS_Unidirectional_Generic | C20617916
IC1 | SOTFL50P160X60-6N | 1 | TPS61023 | C919459
J4, J6 | PH2PWB | 2 | PH-2PWB | C2905019
L1 | XEL4030102MEC | 1 | XEL4030-102MEC | C5441341
LED1, LED3 | 0603 | 2 | LED_R | C2286
LED2 | 0603 | 1 | LED_W | C2290
Q1 | SOT-23 | 1 | BSS138 | C40912
Q2 | SOT-23 | 1 | AO3400A | C20917
R1 | 0603 | 1 | 10K | C98220
R10, R12 | 0603 | 2 | 2KΩ | C22975
R11, R13, R3, R6 | 0603 | 4 | 100K | C14675
R2 | 0603 | 1 | 732K | C246003
R4, R5, R8 | 0805 | 3 | 10K | C17414
R7 | 0603 | 1 | 1.5KΩ | C114668
R9 | 0603 | 1 | 150Ω | C114608
S1 | SW_TL1105DF160Q | 1 | TL1105DF160Q | C273469
U1 | BATT_Charger_SOT-23-5_Min_Silk | 1 | MCP73831T-2ACI/OT | C424093

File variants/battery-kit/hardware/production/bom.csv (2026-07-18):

Designator | Footprint | Quantity | Value | LCSC Part #
C1 | 0603 | 1 | 0.1uF | C14663
C10 | 0402 | 1 | 1uF | C14445
C12, C15, C16, C5, C6 | C_0603 | 5 | 10uF | C96446
C13, C14 | C_0402 | 2 | 10uF | C307415
C7, C8, C9 | 0805 | 3 | 22uF | C98190
D1 | D_SOD-123FL | 1 | PMEG10010ELRX-TP | C7603319
IC1 | SOT-563 | 1 | TPS61023 | C919459
IC2 | TPS62932DRLR | 1 | TPS2116DRLR | C3235557
J1, J10 | PinSocket_1x07_P2.54mm_Vertical_MiniSilk | 2 | Conn_01x07_Socket | C27985232
J2, J3 | PH2PWB | 2 | PH-2PWB | C2905019
J6 | JST_1x04_P1.0mm_Vertical_SMD | 1 | Qwiic_Vertical | C2845372
L1 | IND-SMD_3P-CD75 | 1 | 3 Legged Inductor | C49338546
L2 | XEL4030102MEC | 1 | XEL4030-102MEC | C5441341
LED1 | 0402 | 1 | LED_G | C965793
LED2 | 0402 | 1 | LED_R | C25503345
LED3 | 0402 | 1 | LED_W | C51933306
Q1 | SOT-23 | 1 | 2N7002 | C8545
Q4 | DMP3007SCG7 | 1 | DMT10H009LCG-7 | C461105
R1 | 1206 | 1 | 30mΩ | C7467247
R10 | 0402 | 1 | 1kΩ | C106235
R11, R17 | 0603 | 2 | 100KΩ | C14675
R12 | R_0402 | 1 | 732K | C137940
R13, R21 | R_0402 | 2 | 100K | C25741
R14, R16, R18, R19, R8 | R_0402 | 5 | 10KΩ | C25744
R15, R4 | R_0402 | 2 | 30KΩ | C138008
R2 | R_0603 | 1 | 10Ω | C22859
R20 | R_0402 | 1 | 22Ω | C25092
R22 | R_0402 | 1 | 220K | C2909335
R3 | R_0603 | 1 | 2.2Ω | C22939
R5, R6, R7 | R_0402 | 3 | 5.1KΩ | C25905
R9 | R_0402 | 1 | 150Ω | C25082
S2 | TS1088AR02016 | 1 | TS-1088-AR02016 | C720477
U1 | BATT_Charger_SOT-23-5_Min_Silk | 1 | LP4060B5F | C517259
U2 | DFN-8_3x3mm_P0.65mm_EP2.25x1.5mm | 1 | AP7361C-3.3V | C151007
U3 | SOT-23-5 | 1 | INA180A3 | C122882
U4 | SOT-23-6 | 1 | UCC27511ADBV | C2676982

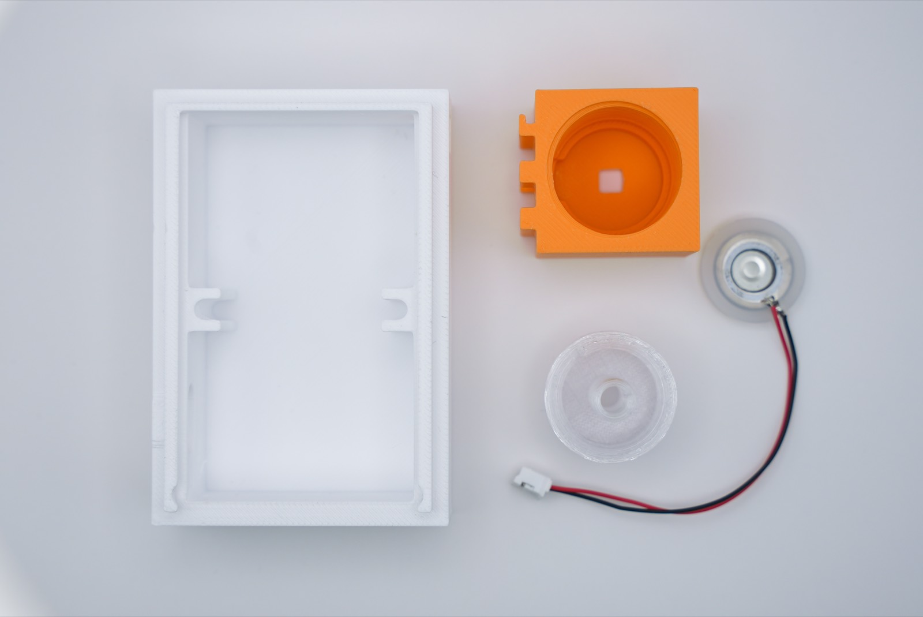
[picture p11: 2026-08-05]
docs/assets/photos/enclosure-01-parts.jpg

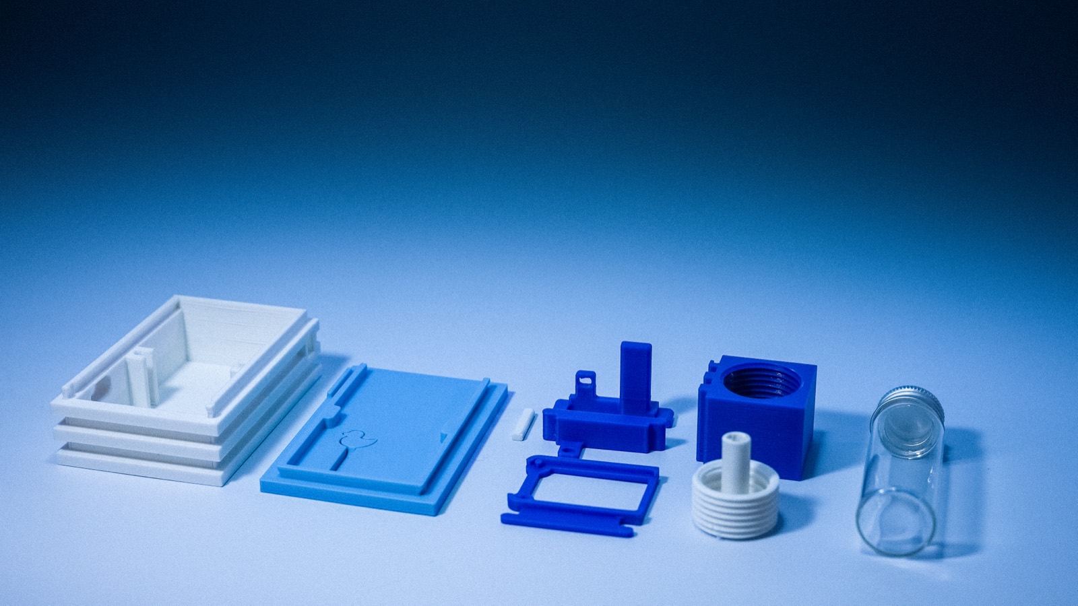
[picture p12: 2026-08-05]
docs/assets/photos/enclosure-parts-studio.jpg

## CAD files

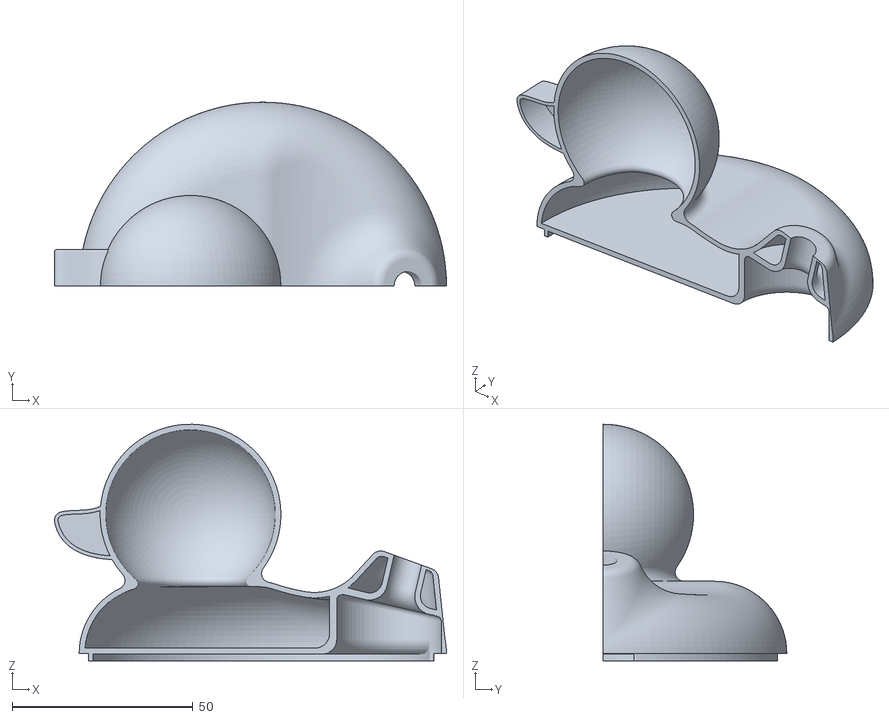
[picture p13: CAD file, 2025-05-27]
EnclosureDesignMaterials/DuckyPart/duck1.stl
108.4 x 50.8 x 65.4

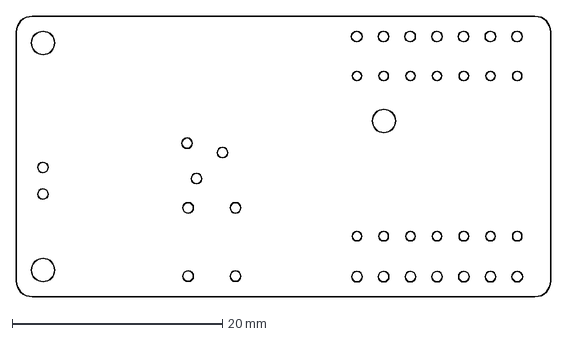
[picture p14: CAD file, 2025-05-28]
EnclosureDesignMaterials/footprint(unit_mm).dxf
50.8 x 26.7 mm

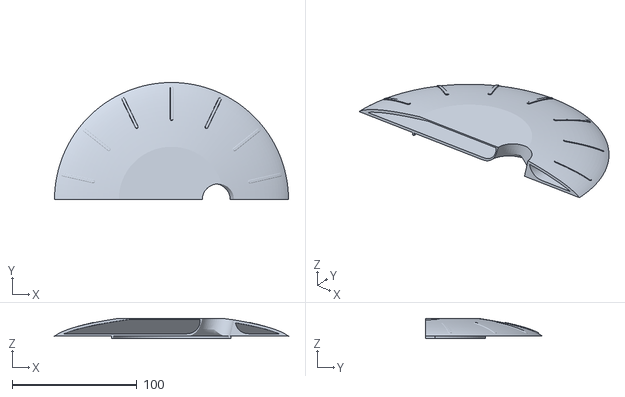
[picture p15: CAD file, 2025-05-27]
EnclosureDesignMaterials/UFOParts/capRimHalf1.stl
187.5 x 93.7 x 16.3

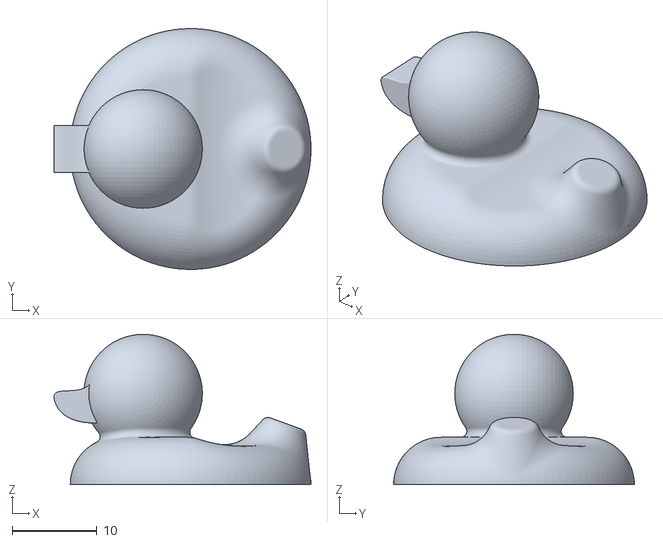
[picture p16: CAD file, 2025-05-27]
EnclosureDesignMaterials/DuckyPart/tinyDuckFilled.stl
30.4 x 28.4 x 17.8

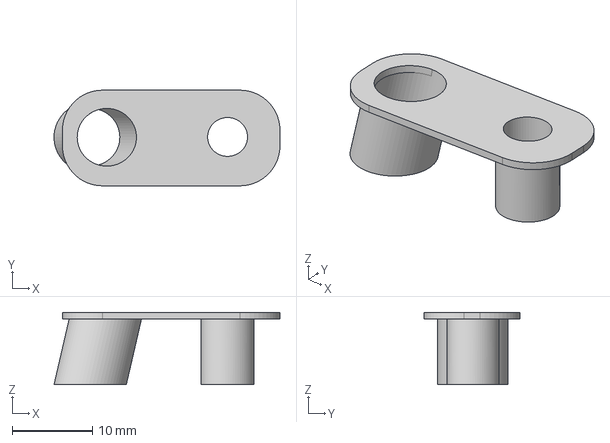
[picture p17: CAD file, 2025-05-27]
EnclosureDesignMaterials/pipes.step
28.2 x 11.9 x 9.00 mm

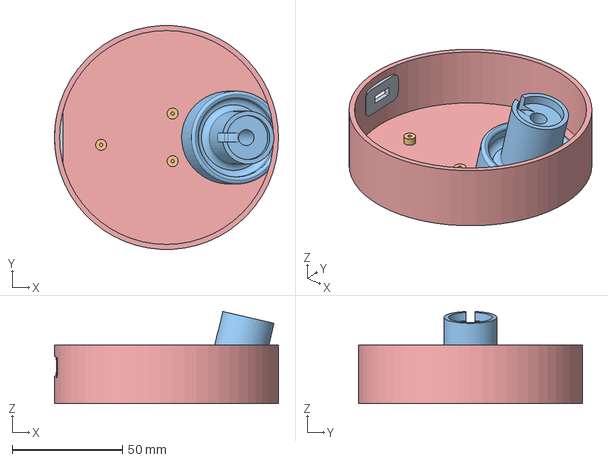
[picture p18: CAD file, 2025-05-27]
EnclosureDesignMaterials/Base.step
101.6 x 101.5 x 41.7 mm

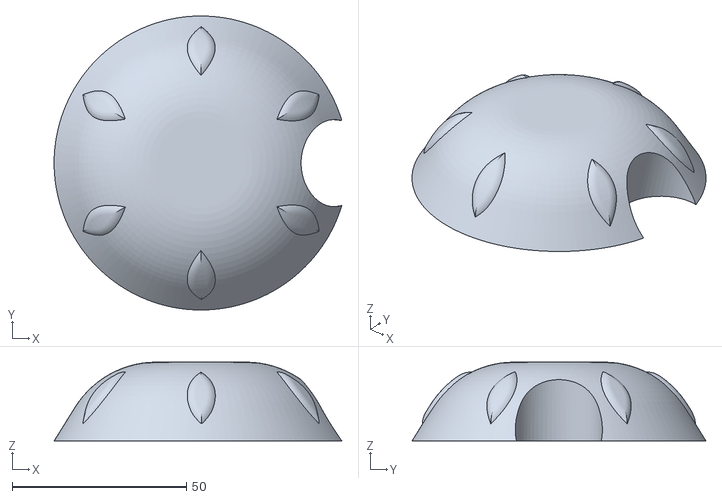
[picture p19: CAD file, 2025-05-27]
EnclosureDesignMaterials/UFOParts/ridingDomeShell.stl
82.6 x 84.4 x 22.6

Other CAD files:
EnclosureDesignMaterials/UFOParts/capRimHalf.stl
EnclosureDesignMaterials/DuckyPart/duck2.stl
legacy/v1-4/EnclosureDesignMaterials/DuckyPart/duck2.stl
legacy/v1-4/EnclosureDesignMaterials/UFOParts/capRimHalf.stl

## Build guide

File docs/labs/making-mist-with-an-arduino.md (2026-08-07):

# Lab: Making Mist With an Arduino

## Introduction

In this lab you'll drive a Programmable Mist Maker from an Arduino Uno (R3
or R4), a Nano 33 IoT, or a Nano 33 BLE using nothing but jumper wires. Both
kits work: the **Battery Kit** normally carries a Seeed XIAO on its back, and
with the XIAO absent its socket is a perfect jumper-wire header; the
**Extension Kit** works the same way once you solder a row of 2.54 mm headers
onto its XIAO footprint.

By the end you'll have mist puffing on a timer, and you'll know why a mist
maker needs a very particular kind of pin to work at all.

### What You'll Need to Know

- [Digital input and output](https://itp.nyu.edu/physcomp/labs/labs-arduino-digital-and-analog/digital-input-and-output-with-an-arduino/)
- [Analog input](https://itp.nyu.edu/physcomp/labs/labs-arduino-digital-and-analog/analog-in-with-an-arduino/)
- What [PWM](https://itp.nyu.edu/physcomp/lessons/analog-output/) is

### Things You'll Need

- A Mist Maker kit with its piezo disc:
    - **Battery Kit** (V0.4.1) with **no XIAO installed** — jumper-ready, and
      the kit this guide walks through, or
    - **Extension Kit** (V0.1) with 2.54 mm headers soldered to the XIAO
      footprint — see [Using the Extension Kit](#using-the-extension-kit)
- An Arduino Uno R3, Uno R4 (Minima or WiFi), Nano 33 IoT, or Nano 33 BLE
- 4–10 male-to-male jumper wires
- A USB cable to your laptop (a laptop port is fine at the default mist
  level), or a USB wall charger
- A small container of water for the disc
- Arduino IDE with the **MistMaker** library v2.5.0 or newer (Library
  Manager → "MistMaker")

## Why 108.7 kHz?

The piezo disc atomizes water only when driven at its mechanical resonance,
about 108.7 kHz. The kit has the power electronics on board — a gate driver
and MOSFET that turn a small logic signal into a strong drive — but the
timing signal comes from your Arduino.

Here's the catch: `analogWrite()` runs at about 490 Hz. That's 200× too slow —
the disc just sits there. Making 108.7 kHz takes a hardware timer, and on most
Arduinos only a few pins are attached to a timer that can do it. The MistMaker
library programs that timer for you, which is why it asks for specific pins:

| Board | Pins that can make mist |
|---|---|
| Uno R3 | 9, 10 |
| Nano 33 IoT | 5, 6, **9**, 10, 11 |
| Uno R4 | 3, 5, 6, **9**, 10, 11 |
| Nano 33 BLE | any digital pin (**9** recommended) |

Pin **9** works on every one of these boards, so this guide wires everything
the same way no matter which Arduino you have. If you pick a pin that can't
do it, the library stops you: `MISTMAKER_ASSERT_MIST_PIN` fails the compile
with the valid pins in the message, and `begin()` returns false at runtime
with the same hint on the Serial Monitor.

## Wire It Up (Battery Kit, USB Mode)

Unplug everything first. Find the kit's empty XIAO socket — two rows of seven
holes, labeled on the silkscreen. Four wires make mist:

- Connect **Arduino 5V** to the kit's **5V pad** (red wire) — powers the kit.
- Connect **Arduino GND** to the kit's **GND pad** (black wire) — shared ground.
- Connect **Arduino 9** to the kit's **D0 pad** (yellow wire) — the 108.7 kHz
  mist signal.
- Connect **Arduino 7** to the kit's **D3 pad** (green wire) — boost enable;
  the kit's ~5 V drive rail stays OFF until this pin goes HIGH.

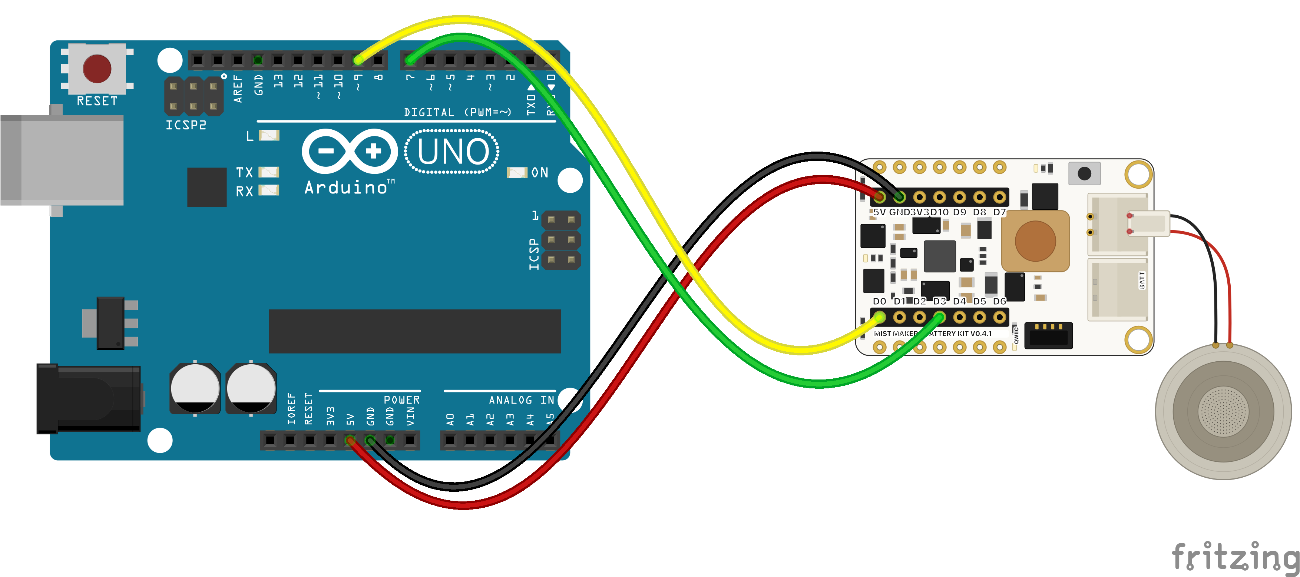
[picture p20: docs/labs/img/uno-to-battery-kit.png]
Uno wired to the Battery Kit


_Figure 1. Uno wired to the Battery Kit. The Uno's headers take jumper ends
directly, so no breadboard is needed. A red wire runs from the Uno's 5V pin
to the kit's 5V pad and a black wire from GND to the kit's GND pad — both on
the kit's top row. A yellow wire runs from pin 9 to the kit's D0 pad and a
green wire from pin 7 to its D3 pad, both on the bottom row. The piezo disc's
red-and-black cable plugs into the kit's DISC connector on the right._

<!-- photo slot: staged photo of the real Uno + Battery Kit wiring -->
_A real build of this wiring._

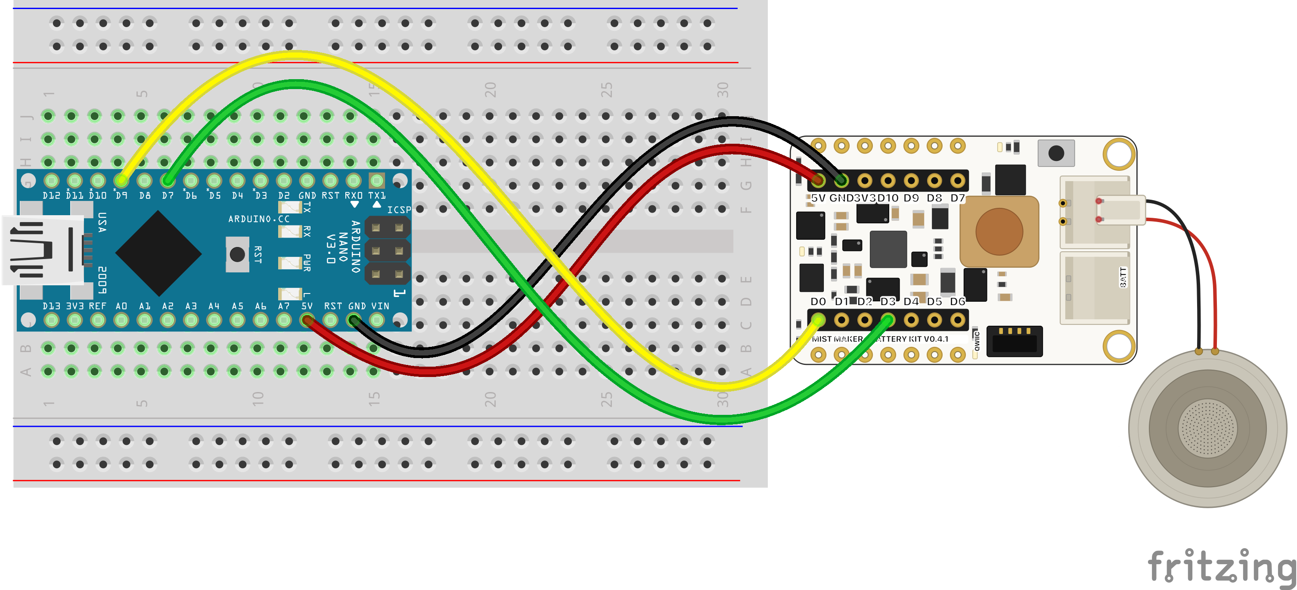
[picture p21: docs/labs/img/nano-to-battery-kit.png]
Nano wired to the Battery Kit


_Figure 2. Nano wired to the Battery Kit — a classic Nano is pictured
(Fritzing has no Nano 33 IoT part), but the 33 IoT and BLE use the same
positions for all four pins. The Nano straddles the breadboard's center
divide at the left end, USB pointing left; the kit sits beside the
breadboard. Yellow runs from the row beside D9 to the kit's D0 pad, green
from D7 to D3, red from the Nano's 5V to the kit's 5V, and black from GND to
GND. The disc plugs into the DISC connector on the right._

### Note on Power

At the default mist level the whole rig draws about 0.3 A — **a laptop USB
port handles that fine**. If you push the mist level up with
`setMaxDuty()` (the turbo setting quadruples the power), switch to a USB
wall charger or the Uno's barrel jack: near peak drive the current can sag a
weak port until the board resets.

### Note on Heat

The kit works hard when it mists, and **getting warm is normal**. The
inductor — the chunky component near the piezo connector — gets genuinely
**hot** during long runs and hotter at higher mist levels. Don't touch it
while misting or right after, and give the board airflow rather than boxing
it in.

### Note on the Nano's 5V Pin

Out of the box the Nano 33 IoT's and Nano 33 BLE's 5V pin is **not
connected** — Arduino ships them that way to protect 3.3 V projects. On the
back of the board, find the solder jumper labeled **VUSB** and bridge it with
a blob of solder. After that the 5V pin carries USB voltage and wire 1 works.
(Uno R3 and R4 need no such step.)

## Program It

Open **File → Examples → MistMaker → JumperWireQuickStart**. The whole sketch
is short. First the pin choices, with the compile-time guard:

```cpp
#include <MistMaker.h>

const int MIST_PIN = 9;  // must sit on a fast timer — the check below explains
MISTMAKER_ASSERT_MIST_PIN(MIST_PIN);

const int BOOST_ENABLE_PIN = 7;

MistMaker mist(MIST_PIN, BOOST_ENABLE_PIN, -1, -1);
```

The two `-1`s mean "no current-sense pin, no LED pin" — you haven't wired
those yet. In `setup()`, start the library and stop if the pin was wrong:

```cpp
void setup() {
  Serial.begin(115200);
  if (!mist.begin()) {
    while (true) {}  // wrong mist pin — the Serial message names the good ones
  }
}
```

The loop is the mist version of Blink:

```cpp
void loop() {
  mist.turnOn();
  delay(6000);
  mist.turnOff();
  delay(3000);
}
```

Pick your board in **Tools → Board**, upload, and set the disc in its water
container. Within a few seconds: six seconds of mist, three seconds of rest,
repeating. That's all it takes.

Try `mist.setLevel(80)` in place of `turnOn()` — mist dims like an LED, 0 to
255.

## My Mist Won't Start!

**Nothing happens at all.** Check the disc is seated in water — a dry disc
makes no visible mist. On the Battery Kit, check wire 4 (pin 7 → D3): the
kit's drive rail boots OFF and stays off until the sketch raises that pin.

**The Arduino resets every time mist starts.** The power source is sagging —
usually a raised mist level, a worn cable, or a weak hub port. Try the
default level first; for higher levels use a wall charger or the barrel
jack.

**The compiler stopped with a message about the mist pin.** Good — that's the
library catching a pin that can't make 108.7 kHz. Move the mist wire and the
`MIST_PIN` constant to a pin from the table above.

**Mist worked, then got weak and erratic.** Two usual suspects. First, the
water level — the disc needs water contact, and running low is exactly what
the water-detection variation below is for. Second, the wick's fit: it needs
to sit **right on the disc, just touching**. Too far away and the disc loses
its water supply; pressed too tight and the wick damps the piezo's vibration.
Either way the mist weakens — reseat the wick so it rests against the disc
without squeezing it.

If water and wick check out and the mist is still dim, **swap in a fresh
piezo disc**. Discs wear out — and in particular, a disc that runs for long
stretches **without water can be permanently damaged** and never mist well
again. (That's the practical reason for the water-detection variation below:
it stops the drive before a dry run hurts the disc.)

**Current reads 0 mA / WaterDetect says "no disc found" with a disc right
there.** The kit's sense amplifier has no power. In USB mode it's fed by the
orange 3.3V wire (Arduino 3.3V → kit 3V3 pad) — without it every current
reading is zero. Add the wire; on battery mode the kit powers the amplifier
itself.

## Using the Extension Kit

The Extension Kit rides the breadboard. It ships with bare through-hole
pads on its XIAO footprint — solder in **male 2.54 mm header pins** and it
mounts straddling the breadboard's center divide, exactly like a Nano (its
two pin columns are the same 0.6 in apart). It has no battery and no boost
enable (its drive rail is live whenever powered), so three wires make mist:

- Connect **Arduino 5V** to the breadboard row beside the kit's **5V pin**
  (red wire) — powers the drive rail directly.
- Connect **Arduino GND** to the breadboard row beside the kit's **GND pin**
  (black wire) — shared ground.
- Connect **Arduino 9** to the breadboard row beside the kit's **D0 pin**
  (yellow wire) — the 108.7 kHz mist signal.

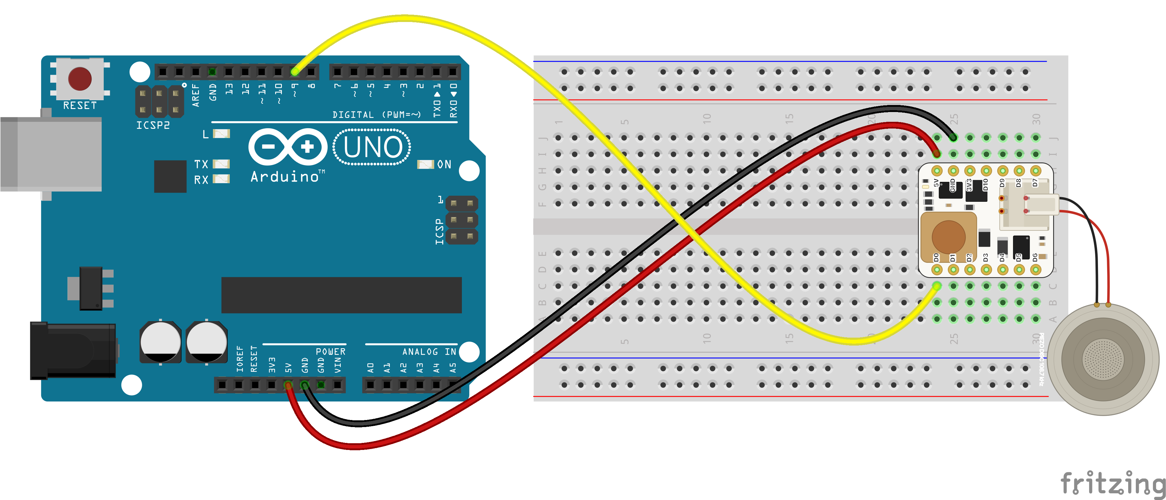
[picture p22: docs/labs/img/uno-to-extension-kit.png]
Uno wired to the Extension Kit on a breadboard


_Figure 3. Uno wired to the Extension Kit. The kit, soldered to male header
pins, mounts on the breadboard straddling the center divide. A red wire runs
from the Uno's 5V to the breadboard row beside the kit's 5V pin, a black wire
from GND to the row beside GND, and a yellow wire from pin 9 to the row
beside D0. No enable wire — the drive rail is live whenever power arrives.
The disc plugs into the kit's piezo connector on the right._

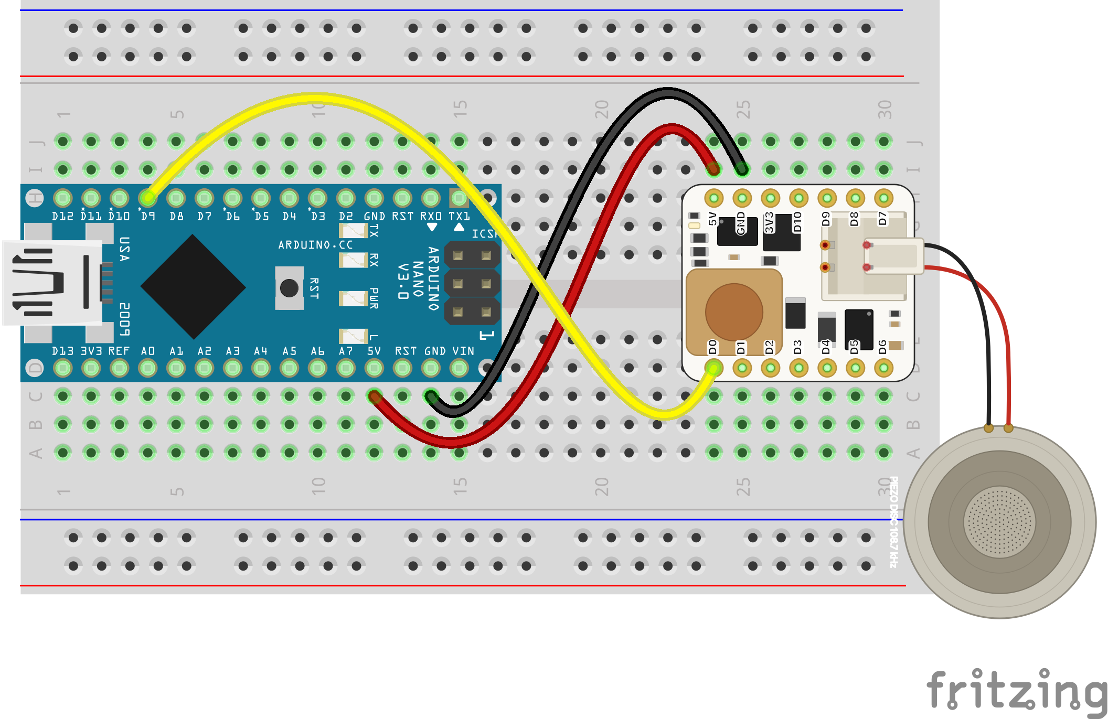
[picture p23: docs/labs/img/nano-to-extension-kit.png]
Nano wired to the Extension Kit on a breadboard


_Figure 4. Nano wired to the Extension Kit — both boards share one
breadboard, each straddling the center divide. Yellow runs from the row
beside the Nano's D9 to the row beside the kit's D0, red from the Nano's 5V
to the kit's 5V, and black from GND to GND. Three wires, no enable — the
drive rail is live whenever power arrives. The disc plugs into the kit's
piezo connector on the right._

In code, use the Extension preset (or pass `-1` for the enable pin):

```cpp
MistMaker mist(MistMakerExtensionV01());
```

Water detection works here too: orange 3.3V → 3V3 pad, blue A1 → D2 pad.
The battery, button, and LED variations are Battery-Kit only — this board
has none of that hardware. The same power and heat notes apply.

## The Uno vs the Nano 33 IoT vs the Uno R4 vs the Nano 33 BLE

- **Logic levels.** The Uno R3 and R4 are 5 V boards; the Nano 33 IoT and
  BLE are 3.3 V. The kit's signal pads (D0 and D3) are inputs that accept
  either, which is why one wiring diagram serves every board here.
- **The 5V pad is power, not signal.** It feeds the mist driver and draws up
  to half an amp, so it belongs on your board's 5V supply pin — never on a
  GPIO. A GPIO can't source that much current, and on a 3.3 V Nano, 5 V on
  an I/O pin can destroy it.
- **Mist resolution.** The mist signal has 147 brightness steps on the R3
  and BLE, and 442 on the Nano 33 IoT and R4 (their timers run faster).
  You'll only notice in slow fades at the dimmest levels.
- **Timer sharing.** On the R3, the mist borrows Timer1: the `Servo` library
  and `analogWrite()` on pins 9/10 would break the mist. On the Nano 33 IoT,
  avoid `analogWrite()` on pins 5, 6, 10, A2, A3 while misting; pins 4 and 7
  still dim LEDs fine. On the R4 and the BLE there's no conflict at all.
- **Uploading.** The Nanos and R4 have native USB — the port can vanish and
  reappear during upload; that's normal.

## Get Creative

Mist responds to anything a sensor can measure. Breathe on a stretch sensor
and have the mist breathe back (`Breath` example). Put mist on a doorway
with a distance sensor. Cross two misting doorways. The `setLevel()` scale
makes mist a dimmable material, like light — what does a *gesture* of mist
look like?

## Going Further

Everything so far is the whole build. The rest is optional — each
add-on is a couple more wires and one more thing the kit can tell you
or do.

### Run on Battery

The Battery Kit powers itself from its own cell — then the Arduino only
supplies signals. Wiring drops to three wires:

- Connect **Arduino GND** to the kit's **GND pad** (black wire).
- Connect **Arduino 9** to the kit's **D0 pad** (yellow wire).
- Connect **Arduino 7** to the kit's **D3 pad** (green wire).

Remove the red 5V wire, and if you added the 3.3V wire from the
water-detection variation, remove that too (on battery the kit drives its
own 3.3 V rail).

### Water Detection

The kit measures the disc's current draw, and from it can tell a disc in
water from a dry disc from no disc at all. Two more wires:

- Connect **Arduino 3.3V** to the kit's **3V3 pad** (orange wire) — powers the
  kit's sense amplifier (USB mode only; remove on battery power).
- Connect **Arduino A1** to the kit's **D2 pad** (blue wire) — the
  current-sense signal.

Change the constructor's first `-1` to `A1`, or use the full preset (below).
Then run the **WaterDetect** example: it probes the disc in every off-window,
stops when the water runs out, and resumes when you refill. Run
`autoCalibrateSense()` once (send `'c'` in the Serial Monitor) — your
Arduino's ADC differs a little from the board the default thresholds were
measured on.

### Battery and Power Source

Plug a LiPo cell into the kit's BATT connector and two more wires tell you
how full it is — and whether the kit is running on it at all:

- Connect **Arduino A0** to the kit's **D1 pad** (purple wire) — battery
  voltage, through a divider on the kit.
- Connect **Arduino A2** to the kit's **D8 pad** (white wire) — power status:
  high on USB, low on the cell.

Why both: with USB plugged in, the cell is charging, so its voltage says
nothing about how much charge is left. The status wire is what lets the
library tell the two situations apart.

```cpp
mist.readBatteryVolts();   // volts at the cell
mist.batteryPercent();     // rough state of charge
mist.usbPresent();         // true on USB, false on the cell
```

Run the **BatteryPowerTest** example to watch all of it live.

### The Kit's Button and LED

The Battery Kit has its own button and white LED. Two wires bring them in:

- Connect **Arduino 2** to the kit's **D6 pad** (grey wire) — the button. It
  reads high while pressed; the kit has its own pull-down, so nothing else
  is needed.
- Connect **Arduino 4** to the kit's **D7 pad** (brown wire) — the LED. The
  library lights it whenever the mist is on.

```cpp
if (mist.buttonPressed()) mist.turnOn();
else                      mist.turnOff();
```

The **ToggleSwitch** and **PushButton** examples build on this — `ToggleSwitch`
follows the level like the snippet above (a latching switch runs the mist until
you flip it off), while `PushButton` debounces the press edge so each press of a
momentary button flips the mist on or off.

### Everything Wired

All nine wires at once — use the preset instead of listing pins, it's the
same map on every board here:

```cpp
MistMaker mist(MistMakerBatteryKitV041());
```

| Kit pad | Arduino pin | Wire | What it does |
|---|---|---|---|
| 5V | 5V | red | powers the kit |
| GND | GND | black | shared ground |
| D0 | 9 | yellow | mist signal |
| D3 | 7 | green | boost enable |
| 3V3 | 3.3V | orange | powers the sense amp (USB mode) |
| D2 | A1 | blue | current sense |
| D1 | A0 | purple | battery voltage |
| D8 | A2 | white | power status (USB vs cell) |
| D6 | 2 | grey | button |
| D7 | 4 | brown | LED |

---

*This guide follows the format of the
[ITP Physical Computing labs](https://itp.nyu.edu/physcomp/labs/). Library:
[MistMaker](https://github.com/owochel/MistMaker) v2.5.0+. Hardware:
OSHWA US002742.*

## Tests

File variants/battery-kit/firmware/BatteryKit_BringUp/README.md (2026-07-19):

# BatteryKit_BringUp

Per-feature hardware verification for the **Battery Kit V0.4 / V0.4.1** (pins D0–D7 are identical on V0.3; the `u` USB/mux test needs V0.4+). No MistMaker library required — flash this first on a freshly assembled board.

**Dependencies:** none. **Board:** XIAO ESP32-C6 (`XIAO_ESP32C6` in Tools > Board).

## Automated self-test (start here)

**Hold the onboard button ≥ 1.5 s** (or send `a` over serial @ 115200) and the sketch runs the automatable slice of the V0.4 acceptance protocol end-to-end — about 10 seconds, disc in water recommended:

| Row | Measures | Pass window |
|---|---|---|
| `RESET` | Last reset reason | anything but `BROWNOUT` |
| `PWR_SRC` | D8 mux status, 40 reads must agree | stable HIGH (USB) or LOW (cell) |
| `VBAT` | Battery divider on D1 | 2.80–4.40 V pass · ≤ 0.5 V / > 4.40 V fail (board fault) · in between = info (discharged cell — charge & re-run) |
| `IDLE_MA` | INA180 zero, rail off | ≤ 10 mA |
| `GATE_OFF` | Full PWM with boost **disabled** | ≤ 10 mA — proves D3 gates the rail |
| `LOAD_MA` | 50% duty burst ≈ 1 s | 60–115 mA dry · 115–280 mA in water · < 10 mA = no disc (skip) |
| `VBAT_SAG` | Vbatt during the burst | info — real sag only on the cell |
| `GAUGE` | SoC gating on power source | on USB: reports "charging, SoC N/A" |
| `LED` | LED1 triple-blink | operator check — watch it |
| `BUTTON` | The trigger itself (or a 5 s press window) | press seen |
| `HANDOFF` | USB↔cell flip counter | info — needs the manual unplug test below |

The run ends with `VERDICT: PASS/FAIL (…counts…)`, one machine-parseable line (`SELFTEST,BATTERY_KIT,<fw>,<verdict>,<counts>` — grep `^SELFTEST,` when batch-logging), and the list of steps that still need hands: multimeter cross-check, the unplug/replug handoff, charge-LED behavior, the phone/radio test, and the duty sweep.

A short button press still toggles the mist (now on release); everything below remains for probing features one at a time.

## Checklist (serial @ 115200)

| Do | Verifies |
|---|---|
| press button | Button wiring — mist + LED toggle (hold ≥ 1.5 s = self-test) |
| `a` | Automated self-test (table above) |
| `t` | Boost rail (D3) + PWM (D0) — disc in water should mist |
| `c` | INA180 current reading on D2 |
| `u` | Power-mux status on D8 (V0.4) — reads USB present; meter TP3 for the cell case |
| `b` | Battery divider on D1 — auto-tagged valid only when on the cell |
| `s` | CSV stream (mA + Vbatt + USB) for the Serial Plotter |
| `0`–`9` | Duty 0–90% dimming |
| unplug USB, replug, `u` | **Mux handoff** — flip counter + boot reason prove the USB↔cell switchover didn't reset the MCU |
| `h` | Help |

Expected at duty 64: no disc ≈ 0 mA · dry disc ≈ 70–100 mA · disc in water ≈ 130–200 mA.
Battery: 4.2 V full · <3.45 V low · <3.20 V critical.

### The `u` test — power mux status (V0.4)

D8 is the TPS2116 **ST** (status) pin, divided down through R21 (100K) / R22 (150K):

| State | D8 | Meaning |
|---|---|---|
| USB plugged in | **HIGH** (~2.6 V) | mux on VIN1 (USB) — Vbatt tracks the *charger*, not SoC |
| running on cell | **LOW** (~0 V) | mux on VIN2 (battery) — Vbatt is a **valid** state-of-charge |

`b` and `[STAT]` always print the voltage + OK/LOW/CRITICAL tag, and append `[USB - charging]` when D8 is HIGH so you know the number isn't a state-of-charge. This is the basis for the library's fix to the V0.3 false low-battery shutdown.

> **Serial caveat:** on this board USB *is* the serial link (native USB-Serial-JTAG), so over the console D8 essentially always reads HIGH. To confirm the LOW/cell state, meter **TP3** (or D8) with the cell in and USB out — you can't watch it flip live over serial.
>
> D8 must be a plain `INPUT` — the R21/R22 divider sets the level, so an internal pull would flip the reading. On V0.3 D8 is an unconnected spare, so `u` is meaningless there.

### The handoff test — live unplug/replug (V0.4)

The TPS2116 switches sources **break-before-make**: for ~1.3 ms neither input drives the rail, and the board must ride through on its capacitors (the 3.3 V handoff also involves Q1 re-enabling the onboard LDO). The sketch counts every USB↔cell flip in RAM and prints the **reset reason** at boot, so the test works even though serial dies while unplugged:

1. Cell plugged in, mist running (`t`), USB connected.
2. Unplug USB — mist should keep running from the cell. Wait a few seconds.
3. Replug USB, reopen serial, press `u`.
4. **Pass:** handoff count ≥ 2 and boot reset still reads `power-on` (a fresh `BROWNOUT` line means the gap dipped too deep — check C6/C12/C15 soldering).

### Power notes (as-built V0.4 June run · V0.4.1 July 2026 production run)

- **Boost rail at power-on differs by revision.** V0.4 (R8 pull-up): the ~5 V rail is **live from power-on** until the sketch drives D3 low in `setup()` — don't be surprised by 5 V on a scope before boot. **V0.4.1 (R8 pull-down): the rail is dead and LED2 stays OFF until firmware raises D3** — a dark LED2 at plug-in is correct, not a fault. The piezo stays off regardless (R11 holds the MOSFET gate down).
- **D8 logic-high moved:** ~2.6 V on V0.4 (R22 = 150 kΩ) → **~3.1 V on V0.4.1 (R22 = 220 kΩ)** — the spin widened the USB-detect margin from 0.2 V to 0.66 V.
- **Deep-sleep drain:** ~0.3–0.5 mA on V0.4 (R8 re-enables the boost when the GPIO releases) → **~0.25 mA on V0.4.1** (divider + LDO only).
- Charge current is **~196 mA** (R6 = 5.1 kΩ on the LP4060) — a deliberate thermal derate from the 500 mA design. LED1 (green) lit = charging; a 500 mAh cell takes ≈ 3 h from empty.
- The battery divider (R18/R19) is hard-wired and draws a constant **~210 µA** from the cell — negligible in use, but don't expect shelf-storage battery life with a cell left plugged in.

Pass everything? Move on to the [MistMaker library](https://github.com/owochel/MistMaker) (≥ 2.2.0) examples — start with `Blink`; battery monitoring there self-gates on the same D8 mux status this sketch just verified.

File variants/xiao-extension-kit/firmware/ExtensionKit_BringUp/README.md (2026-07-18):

# ExtensionKit_BringUp

Per-feature hardware verification for the **Extension Kit V0.1**. No MistMaker library required — flash this first on a freshly assembled board.

**Dependencies:** none. **Board:** XIAO ESP32-C6 (`XIAO_ESP32C6` in Tools > Board).

## Automated self-test (start here)

**Press the XIAO's BOOT button** (the Extension has no button of its own — BOOT is safe to press after boot) or send `a` over serial @ 115200. The sketch runs a few-second pass/fail checkout, disc in water recommended:

| Row | Measures | Pass window |
|---|---|---|
| `RESET` | Last reset reason | anything but `BROWNOUT` |
| `IDLE_MA` | INA180 zero, PWM off | ≤ 10 mA |
| `LOAD_MA` | 50% duty burst ≈ 1 s | 60–115 mA dry · 115–280 mA in water · < 10 mA = no disc (skip) |
| `BOOT_BTN` | The trigger itself (or a 5 s press window) | press seen |

The run ends with `VERDICT: PASS/FAIL` plus one machine-parseable line (`SELFTEST,EXTENSION_KIT,<fw>,<verdict>,<counts>` — grep `^SELFTEST,` when batch-logging). Same report format as the Battery Kit self-test, so batch QC across both kits logs identically.

## Serial checklist (115200 baud)

| Send | Verifies |
|---|---|
| `a` (or BOOT press) | Automated self-test (table above) |
| `t` | PWM out of D0 — disc in water should mist |
| `c` | One INA180 current reading on D2 |
| `s` | CSV stream for Arduino Serial Plotter — compare dry vs wet disc |
| `0`–`9` | Duty 0–90% — mist should visibly dim |
| `h` | Help |

Expected at duty 64 (50% of full): no disc ≈ 0 mA · dry disc ≈ 70–100 mA · disc in water ≈ 130–200 mA.

Pass everything? Move on to the [MistMaker library](https://github.com/owochel/MistMaker) (≥ 2.1.0) examples.

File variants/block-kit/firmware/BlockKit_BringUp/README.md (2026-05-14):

# BlockKit_BringUp — bare-metal per-feature test sketch

The tiny sketch you flash when something on the bench feels off and you want to
isolate the hardware before re-engaging the full production UX. **No state
machine, no animations, no smoother** — press the button and verify each
peripheral works in isolation.

For normal daily use flash [`../BlockKit_Production/`](../BlockKit_Production/)
instead.

## What it does

| Trigger | Effect |
|---|---|
| Press button (D6) | Toggle mist (D0 @ 50 % PWM) + boost rail (D3) + all 14 LEDs at PWM 80 |
| Send `t` | Same as a button press |
| Send `w` | LED chase: each of the 14 LEDs lights for 1 s in top→bottom order |
| Send `c` | Current-sense dump: mean / min / max ADC count and mA of 100 reads |
| Send `h` | Help |

Every 250 ms a `[STAT]` line prints with raw button, raw reed, mist on/off,
raw ADC and computed mA — so you can leave the Serial Monitor open and
visually confirm the hardware is responding without waiting for an event.

## Bring-up checklist

1. **Boot output** — confirm the `[APP] PIN_*=… (GPIO N)` lines match the
   XIAO ESP32-C6 mapping (D0=0, D2=2, D3=21, D6=16, D7=17, D10=18). If not,
   the wrong board is selected in Tools→Board.
2. **D7 status LED** — boots dim (~10 %). Goes off when the toggle is ON.
3. **Button** — pressing should print `[BTN] press` followed by an `[OUT]`
   line. If `[BTN]` never appears, check the 10 k pull-down on D6 and the
   button PCB harness.
4. **Boost rail** — when the toggle goes ON, the red LED2 on the Driver
   PCB should light (D3 high = TPS61023 enable).
5. **Mist** — once boost is up the piezo should mist. Hold the container
   above it to verify.
6. **LED ring** — all 14 LEDs come up at PWM 80 (uniform bright). If
   IS31FL3731 fails to init you'll see `[LED] IS31FL3731 not found at 0x74`
   on the Serial banner; check I2C wiring (D4/D5) and that the LED PCB has
   3 V3 power.
7. **LED order** — send `w`. The chase walks LEDs in the order defined by
   `LED_MAP[]` in `pins.h`; physical order should be top→bottom. If
   reversed, swap the array.
8. **Reed switch** — drop a magnet on the reed; `[STAT]` row shows
   `reed=1`. Lift; back to `reed=0`. (Note: the BringUp sketch does NOT
   gate mist on the reed — that's a production-firmware feature.)
9. **Current sense** — with the toggle OFF send `c`; mA should be near 0.
   Toggle ON, send `c` again; mA should jump to ~100–200 mA (depending on
   water load).

## Install

Same as production:

1. Arduino IDE 2.x with **esp32 by Espressif Systems** v3.x.
2. Install [David's IS31FL3731 fork](https://github.com/Dav1dyang/Adafruit_IS31FL3731)
   into the Arduino libraries folder.
3. Open `BlockKit_BringUp.ino`, select board **XIAO_ESP32C6**,
   USB CDC On Boot **Enabled**, Upload.

## Files

| File | Purpose |
|---|---|
| `BlockKit_BringUp.ino` | Everything — single-file sketch |
| `pins.h` | GPIO assignments + frequency / LED-map constants (no UX tunables) |

Only one library dependency: `Adafruit_IS31FL3731` (David's fork). No
`Adafruit_BusIO` / `Adafruit_GFX` direct calls beyond what the fork pulls in.

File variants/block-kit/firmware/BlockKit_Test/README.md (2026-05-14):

# BlockKit_Test — Phase A bring-up firmware

Block Kit V0.1 firmware that exercises every subsystem (mist PWM, reed switch, button, IS31FL3731 LED ring, D7 indicator LED) **plus** a "scope mode" that streams the INA180 current data so the water-detection algorithm can be designed from real bench data later (Phase B).

Phase A intentionally has **no water-level classifier**. The reed switch is the primary on-gesture (magnetic-on); the button short-press hides the LED strip without touching the mist; long-press ramps the level. One unified `g_userLevel` variable drives both mist PWM duty and LED ring brightness so they move together; while `RUNNING`, the mist drive is additionally modulated by the wave swell at the piezo position so the mist visibly pulses with the LED animation.

## States

Three container-driven states, all transitions handled in `BlockKit_Test.ino::loop()`. A level smoother fades `g_currentLevel` toward whatever the new state's target is in tiny per-tick steps (+2 / 10 ms ≈ 1.3 s 0→255), so every brightness change reads as a continuous slide. The LED driver runs an automatic 1.1 s **crossfade** whenever the mode swaps between BREATH and WAVE — there is never a snap.

LED visibility is **orthogonal** to state: a separate boolean (`g_ledsHidden`, toggled by the short-press button) hides or shows the strip with its own ~640 ms fade. Mist is unaffected by this flag — short-pressing only mutes the visuals; it never stops the diffuser.

| State | When | Mist | LED ring | D7 white |
|---|---|---|---|---|
| `IDLE` *(default boot)* | No container | off | deep-dim exp(sin) BREATH; exhale dwells at black  | dim (~10 %) |
| `RUNNING` | Container docked | **Wave-modulated** at piezo position — mist pulses with the LED swell; trough ≈ 36 % of set level | WAVE — every LED always lit, single slow gaussian swell rising bottom→top over 7.5 s | off |
| `TRANSITION_FROM_RUNNING` | Container just lifted | hard-stopped | Wave dims to 0 (~0.85 s), then auto-enters `IDLE` for the BREATH crossfade | dim (~10 %) |

### Transition map

| From state | Event | To state | Notes |
|---|---|---|---|
| `IDLE` | Container inserted (reed 500 ms) | `RUNNING` | BREATH→WAVE crossfade — dim breath dissolves into slow swell |
| `RUNNING` | Container removed (reed 100 ms) | `TRANSITION_FROM_RUNNING` | **Mist hard-stops** (safety); wave dims naturally as baseLevel ramps 255→0 |
| `TRANSITION_FROM_RUNNING` | Smoother lands at 0 | `IDLE` | Mode→BREATH (WAVE→BREATH crossfade); fast restore (~0.64 s) |
| `TRANSITION_FROM_RUNNING` | Container re-inserted | `RUNNING` | Crossfade engine takes over mid-fade — clean recovery, no special case |
| any state | Button **short-press** | (no state change) | Toggles `g_ledsHidden`. LED render fades to/from 0 over ~640 ms. Mist unchanged. |
| `IDLE` or `RUNNING` | Button **long-press** | (no state change) | Ramps `g_userLevel`; mist + LED brightness follow live (wave traverse rate unchanged)  |

### One level + an orthogonal hide flag

`g_userLevel` (0..255) is the user-set "intensity". It controls:
- **Mist PWM duty** = `(level × MIST_DUTY_MAX) / 255` — level 255 ⇒ 50 % duty (full mist). In `RUNNING` the duty is *further* modulated by the wave swell at the piezo position — see "Wave-mist sync" below.
- **LED ring brightness** — scales the entire render (BREATH cap and WAVE base+swell) uniformly.

`g_targetLevel` is what the current state wants the level to be (0 in `TRANSITION_FROM_RUNNING`, `g_userLevel` otherwise). `g_currentLevel` is smoothed toward target each tick in deliberately tiny steps so the fade reads as continuous, not stepped.

`g_ledsHidden` is the short-press toggle. When set, a per-LED scaler (`g_ledScale`, 0..255 smoothed over ~640 ms) multiplies the `g_currentLevel` handed to `ledRender()`. Mist does NOT see this scaler — so blanking the visuals never stops the diffuser. Long-press to adjust the level still works whether the LEDs are hidden or not (you'll feel the change through the mist).

### Wave-mist sync (RUNNING only)

While `RUNNING`, mist drive is no longer a flat `g_currentLevel`. Each tick the firmware samples the wave's gaussian swell at the **piezo position** (1 LED above index 0, where the piezo disc physically sits) and uses it to modulate the mist:

```
factor (Q8) = MIST_WAVE_TROUGH_Q8 + ((256 - MIST_WAVE_TROUGH_Q8) × gauss_at_piezo) / 256
mist_level  = (g_currentLevel × factor) / 256
```

Because the piezo sits *above* the top LED, the gaussian peaks at the piezo **after** the wave has visibly crossed the top of the strip — so the mist "continues to grow" as the swell passes the top, then dims back down together with the top LED as the wave exits off-screen above. At max user level (255) the mist swings between ~36 % and 100 % of full duty — visible pulse, but proportional to the wave's own 92/255 trough-to-peak ratio so the LEDs you see and the mist you feel feel like one motion.

### Lift-off is a SAFETY event

When the reed opens (container lifted), mist is hard-stopped immediately — boost rail down, PWM 0, the lot. The LED ring continues fading via the smoother, which is purely visual. The reason: no surprise misting after the bottle is physically gone.

## Hardware required

- Block Kit V0.1 (3 PCBs assembled — Driver, Mist & LED, Button)
- Seeed XIAO ESP32-C6
- Piezo mist disc (108.7 kHz)
- Reed switch + magnet on the container module
- USB-C cable for power and serial

V0.1 needs the **reed-to-D10 blue-wire rework** described in `../../hardware/README.md`. Without it, the reed switch will not work.

## Install

1. Arduino IDE 2.x with the **esp32 by Espressif Systems** board package (v3.x).
2. Clone David's IS31FL3731 fork into your Arduino libraries folder:

   ```bash
   cd ~/Documents/Arduino/libraries
   git clone https://github.com/Dav1dyang/Adafruit_IS31FL3731
   ```

   Adafruit_BusIO and Adafruit_GFX (its transitive dependencies) install fine from Library Manager.
3. Open `BlockKit_Test.ino`. Select board **XIAO_ESP32C6**, USB CDC On Boot **Enabled**.
4. **Verify** to compile, then **Upload**.

## Serial console (115200 baud)

On boot you'll see the banner, the resolved pin map, and the command list. Every log line is tagged so you can grep one subsystem:

```
[APP] Block Kit V0.1 bring-up (Phase A)
[APP] PIN_MIST_PWM=D0 (GPIO 0)
[APP] PIN_REED=D10 (GPIO 18)
[APP] state=IDLE (boot, LEDs visible)
[REED] inserted
[APP] -> RUNNING
[MIST] on (boost up)
[STAT] state=RUNNING leds=visible reed=1 btn=0 user=255 cur=140 mist=1 mean_mA=178.2
[PLOT] 178.4,12.3,1
[BTN] long-press start, dir=-1
```

- `[STAT]` prints once a second — a human-readable subsystem snapshot.
- `[PLOT]` is the Arduino Serial Plotter–friendly CSV: `mean_mA, var_mA2, state` at 20 Hz when scope mode is off, or `raw_mA, mean_mA, var_mA2` at 100 Hz when scope mode is on.
- Send `m` to mute `[PLOT]` while you read other lines.

### Commands

| Cmd | Effect |
|---|---|
| `help` | Print this list |
| `l` / `L` / `t` | Hide LEDs / show LEDs / toggle visibility (mist is unaffected) |
| `vN` | Set `g_userLevel` directly, 0..255 (e.g. `v180`) |
| `w` | Run `ledWalk` (lights LEDs 0..13 in sequence — blocks ~14 s) |
| `k` | (Phase B placeholder) recalibrate current-sense baseline |
| `s` | Toggle current-sense scope mode |
| `r` | Dump reed state — raw (LOW=magnet present, HIGH=open) and debounced |
| `m` | Mute / unmute the periodic `[PLOT]` stream |

The LED driver addresses Matrix B of the IS31FL3731 directly via `setLEDPWM(lednum, pwm, 0)` — `lednum` 8..15 are CB1 (top row, LEDs 1..8) and 24..29 are CB2 (bottom row, LEDs 9..14), per IS31FL3731 datasheet Rev F Table 7. BREATH uses a 64-entry exp(sin) curve LUT (asymmetric — lingers at black on the exhale for a dramatic dim-idle); WAVE uses a 64-entry gaussian LUT for the swell shape (σ=4 LEDs, so the bump occupies ~⅓ of the strip at any moment). Both are linear-interpolated for sub-quantum smoothness and pass through a 256-entry 2.2 gamma table — smooth and FPU-free. Mode swaps run a 1.1 s linear crossfade in pre-gamma space.

## Bring-up checklist

1. **Boot output:** confirm `[APP] PIN_*=… (GPIO N)` lines match the XIAO ESP32-C6 expected values (D0=0, D10=18, D2=2, D3=21, D6=16, D7=17). If they don't, the board selected in Tools→Board is wrong.
2. **Walk:** send `w` → 14 LEDs light in sequence with `[LED] walk i=N lednum=M`. If the physical order differs from top→bottom, reorder `LED_MAP[]` in `pins.h`.
3. **D7 indicator:** at boot with no container, D7 should be dim and steady.
4. **Short-press hides LEDs only:** press the button briefly (with or without a container) → `[APP] LEDs hidden …`, the strip fades to dark over ~640 ms. Mist (if a container is docked) keeps running at the same level. Press again → `[APP] LEDs visible`, strip fades back in.
5. **Mist trigger + wave-sync:** dock a container with a magnet → after the 500 ms dwell, `[APP] -> RUNNING`, D3 goes HIGH (red LED2 lights), mist + ring ramp up together. Once steady, the **mist visibly pulses with the swell** — the mist peaks just after the LED swell crosses the top of the strip, then dims back down together with it.
6. **Mist shut-off:** lift the container → `[REED] removed` after 100 ms, **mist hard-stops** (no fade), ring continues fading down, D7 returns to dim.
7. **Long-press ramp:** while RUNNING (or `IDLE`), hold the button → ring + mist dim together (mist still pulses with the wave on top of the dim). Release. Hold again → ramp the other direction. The ramp clamps at 0/255; long-pressing to 0 leaves you at level 0, not in a special "off" state — the LEDs stay visible (just dark), and the next long-press in the other direction brightens back up.
8. **Current data (Phase B prep):** with a docked container at full level, send `s` and open Serial Plotter. Capture `mean_mA, var_mA2` traces for full water, low water, dry disc, no disc.

## Files

| File | Purpose |
|---|---|
| `BlockKit_Test.ino` | `setup()`, `loop()`, 3-state machine, level smoother, serial parser |
| `pins.h` | Pin numbers, tunables, enums — single source of truth |
| `mist.ino` | `mistApply(level)` / `mistHardStop()` — boost gating + PWM scaling |
| `container.ino` | Reed switch debounce + insert/remove edges |
| `button.ino` | Button debounce + short / long-press events |
| `led_driver.ino` | IS31FL3731 (Matrix B) — uniform breathing + LUT interpolation + `ledWalk` |
| `status_led.ino` | D7 white LED — dim-on or off |
| `current_sense.ino` | INA180 ADC at 1 kHz, rolling mean+variance, scope mode |

All `.ino` files are auto-concatenated by the Arduino IDE — there is no build system to configure.

## Phase B follow-ups (not in this build)

- Add `LOW_WATER` state to the machine: warn user (red LED + serial), start a 10-minute shutoff timer, refill cancels.
- Adaptive baseline capture (5 s slosh skip + 25 s average) into RAM.
- Variance threshold tuned from Phase A scope data.
- Battery-low detection requires a V0.2 hardware change (VBAT voltage divider).

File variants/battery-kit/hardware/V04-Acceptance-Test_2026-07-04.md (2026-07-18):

# Battery Kit V0.4 — Acceptance Test Protocol

> **V0.4.1 boards (rev "0-4-1", R8 = pull-DOWN):** two expectations flip vs
> V0.4 — (1) at power-on the ~5 V rail is **DEAD** and **LED2 stays OFF** until
> the sketch starts (boost defaults off now); (2) deep-sleep battery drain
> should measure **~0.25 mA instead of ~0.5+** (divider + LDO only, boost truly
> off). D8 on USB now reads **~3.1 V** (R22 = 220 k). Everything else identical.

**Purpose:** confirm a V0.4 board is 100% functional, including the new ST
power-source sense and battery-reading accuracy. ~20 minutes per board.
**Firmware:** `BatteryKit_BringUp` from `main` (post PR #27). Serial 115200.
**Setup:** piezo disc in water, 1S cell connected, USB to computer, multimeter
handy (inline USB current meter helpful).

## A. Power & boot — 30 s

| Step | Do | Pass |
|---|---|---|
| A1 | Plug USB | `[BOOT] reset: power-on` · `[USB] boot source: USB (VIN1)` · `[BATT]` shows 3.0–4.4 V |
| A2 | Look at LEDs | LED2 (red) ON = 5 V rail up · LED1 (green) ON if cell not full (charging), OFF if full |

## B. Mist drive — 1 min

| B1 | `t` | Mist within ~1 s, D7 LED on |
| B2 | `0`…`9` | Plume visibly follows the level |
| B3 | Press button | Toggles mist (active-high) |

## C. Current sense / water detection — 2 min

`c` at the default duty — three distinct bands prove the sensor chain:

| Condition | Expected `c` |
|---|---|
| Disc in water | **130–200 mA** |
| Disc dry (briefly!) | 70–100 mA |
| Piezo unplugged | ~0–10 mA |

## D. ST pin (the V0.4 headline) — 3 min

| D1 | `u` on USB | "present : mux on VIN1 (USB)" — D8 pin ≈ 2.6–2.7 V on a meter, ST node (TP3) ≈ 4.4 V |
| D2 | Cell in, unplug USB | **Board keeps running** (mist continues if on). Meter D8 → ~0 V |
| D3 | Replug, press `u` | "handoffs since boot: ≥2 … handoff survived, no reset" |

D3 is the **mux handoff test** — it proves the TPS2116's 1.3 ms break-before-make
gap didn't brown out the MCU at normal load. (Serial dies during the unplug;
the counter + reset reason are the after-the-fact proof.)

## E. Battery reading accuracy — 5 min

| E1 | `b` on USB | Voltage + **`[USB - charging, SoC N/A]` tag** — the tag itself proves ST gating works |
| E2 | Multimeter on BATT+ (battery connector) vs `b` | Agree within **±0.05–0.10 V** (divider + ADC calibration) |
| E3 | Resting-voltage truth check on the cell | Run DutySweep_Test `B` (armed battery sweep) — its **duty-0 baseline row** logs resting Vbatt while on the cell; compare to multimeter before/after. ±0.05 V = calibrated |
| E4 | Charging behavior | LED1 ON with a partial cell; inline USB meter shows ~0.2 A above idle; LED1 OFF at full |

## F. Radio + phone — 5 min

| F1 | Flash `PhoneSensors` (WiFi creds + relay `mistcontrol.byproductlab.com`) | Maker appears in the web app's MAKERS panel with live mA/water/RSSI |
| F2 | Slider | Drives mist, watchdog cuts mist ~6 s after closing the app |
| F3 | Music mode | Mist pulses on beats (new build is live) |

## G. Optional: drive-stage health sweep — 3 min

DutySweep_Test, `w` at the default 600 mA limit. A healthy V0.4 matches the
reference curve: **~170–225 mA near-plateau from 18–50% duty**, then 310 (56%)
→ 480 (62%), abort ~68%. A plateau shifted far from this = suspect disc,
water level, or drive stage.

## Known NON-defects (expected on every V0.4)

- **LED3 (white) is dim** — 3.1 V Vf on a 3.3 V GPIO; V0.5 item.
- **~5 V rail live from power-on** until firmware boots (R8 pull-up); piezo stays off.
- **~0.3–0.5 mA drain in deep sleep** (R8 re-enables the boost when the GPIO
  releases); V0.5 item (R8 → pull-down).
- **~210 µA constant divider drain** on the cell (hard-wired R18/R19).
- D8 can't be watched over serial while on battery (USB *is* the serial link) —
  that's what the flip counter and TP3 are for.

**All boxes pass → the board is good.** File one row per board serial if
batch-testing.

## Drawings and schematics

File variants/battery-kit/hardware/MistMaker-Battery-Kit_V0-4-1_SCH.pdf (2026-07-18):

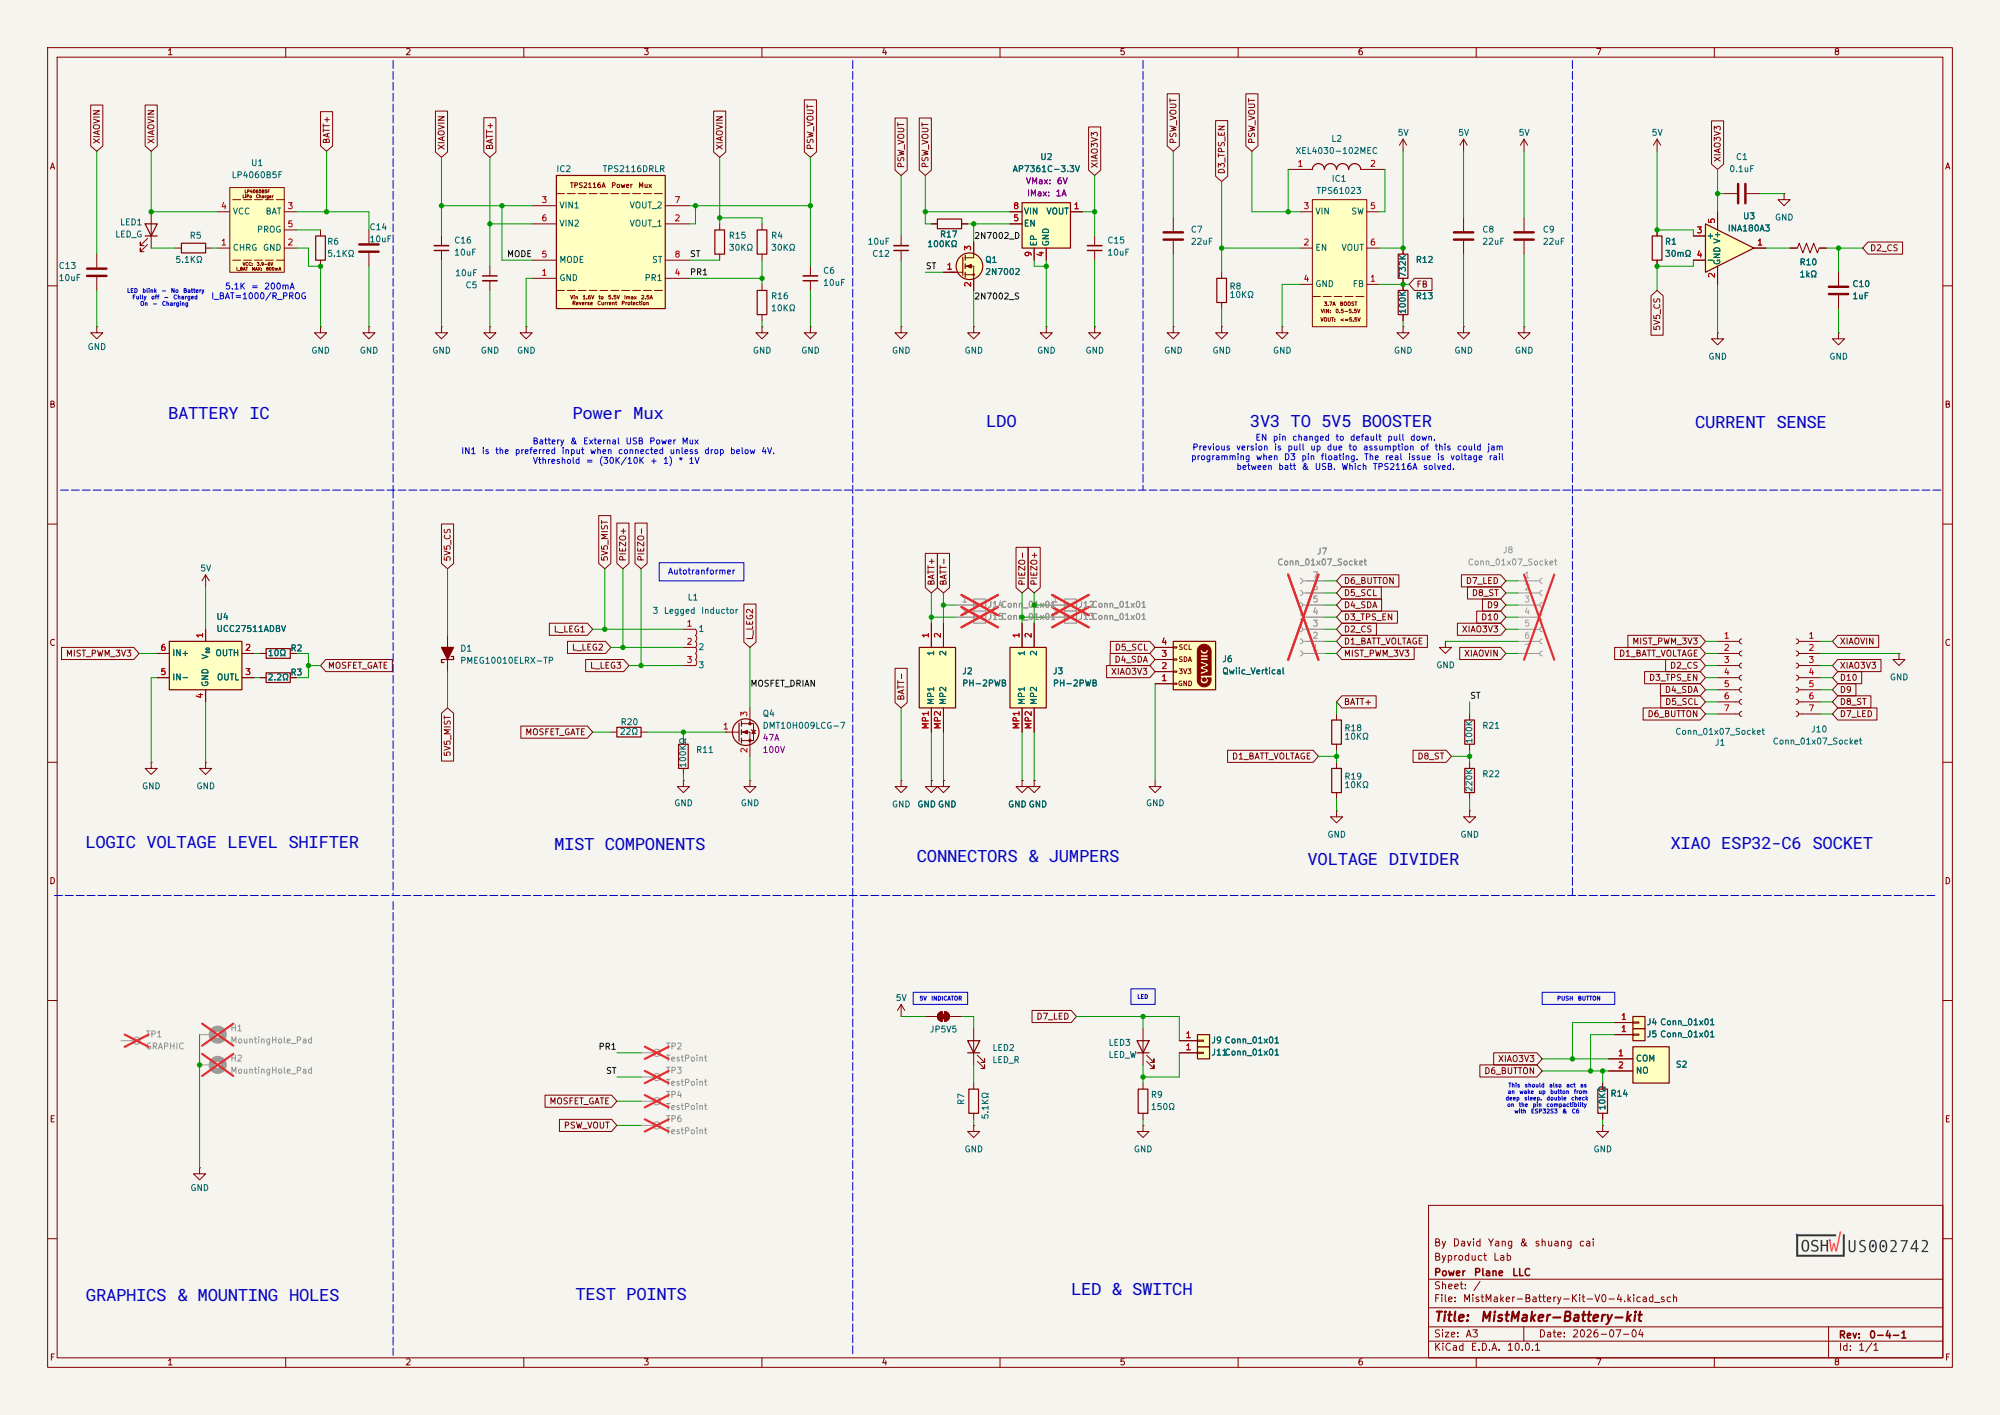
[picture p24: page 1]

Vin 1.6V to 5.5V Imax 2.5A Reverse Current Protection GND 1

LED blink - No Battery Fully off - Charged On - Charging

EN pin changed to default pull down. Previous version is pull up due to assumption of this could jam

Battery & External USB Power Mux

programming when D3 pin floating. The real issue is voltage rail between batt & USB. Which TPS2116A solved. LED & SWITCH

V DD 1 OUTH 2 OUTL 3 GND

2 MP1 MP1 MP2 MP2 GND GND GND GND

deep sleep. double check on the pin compactiblity with ESP32S3 & C6 VOLTAGE DIVIDER

This should also act as an wake up button from

By David Yang & shuang cai
Byproduct Lab
Power Plane LLC
Sheet: /
File: MistMaker-Battery-Kit-V0-4.kicad_sch
Title: MistMaker-Battery-kit

Size: A3 | Rev: 0-4-1 | F Date: 2026-07-04
KiCad E.D.A. 10.0.1 | Id: 1/1

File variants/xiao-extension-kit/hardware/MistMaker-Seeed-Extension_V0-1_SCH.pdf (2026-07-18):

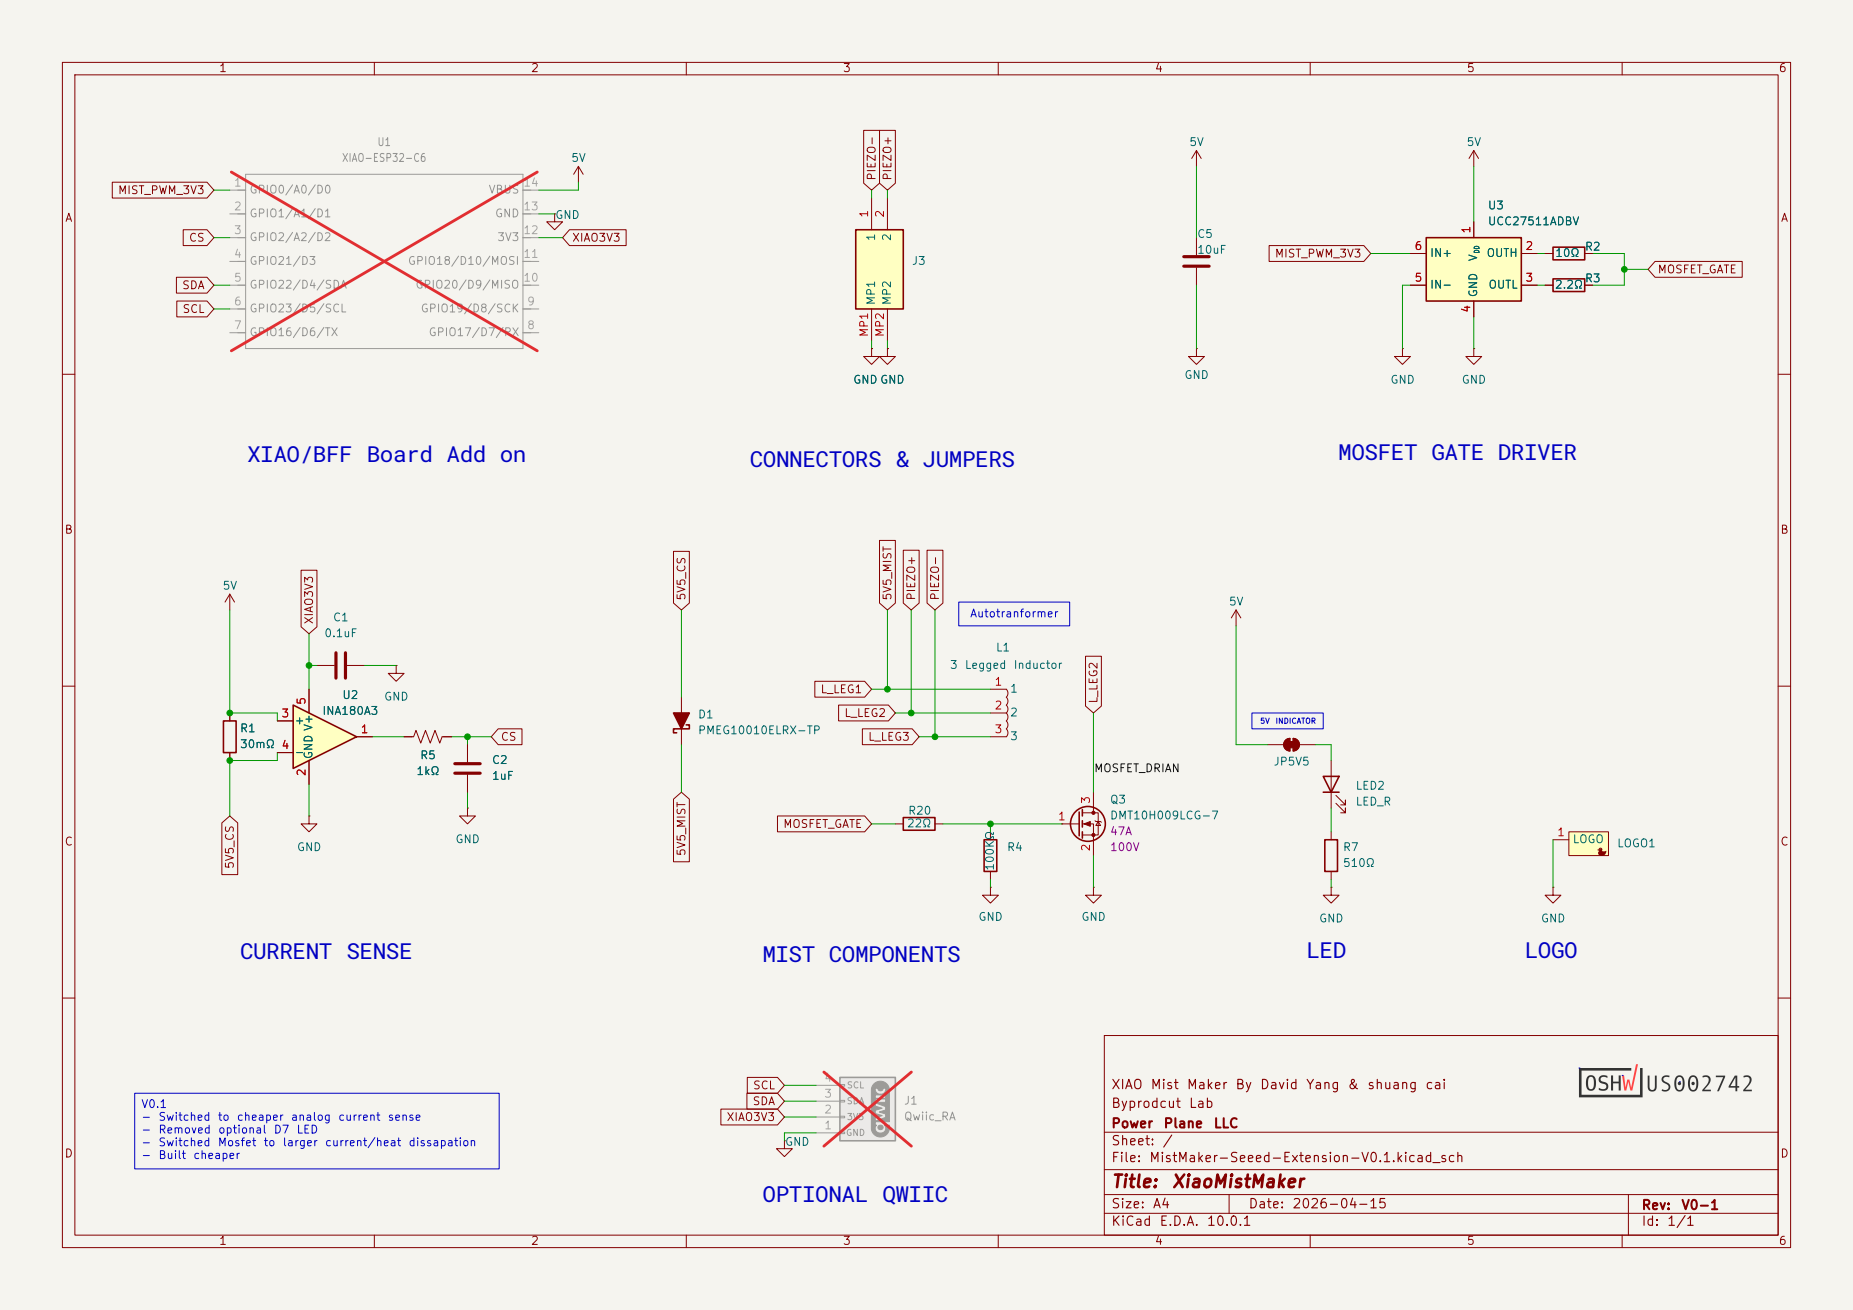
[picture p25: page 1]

V DD 1 OUTH 2 OUTL 3 GND

XIAO/BFF Board Add on

Autotranformer V0.1 - Switched to cheaper analog current sense - Removed optional D7 LED - Switched Mosfet to larger current/heat dissapation - Built cheaper

XIAO Mist Maker By David Yang & shuang cai R20

Byprodcut Lab
Power Plane LLC
Sheet: /
File: MistMaker-Seeed-Extension-V0.1.kicad_sch
Title: XiaoMistMaker

Size: A4 | Rev: V0-1
KiCad E.D.A. 10.0.1 | Id: 1/1

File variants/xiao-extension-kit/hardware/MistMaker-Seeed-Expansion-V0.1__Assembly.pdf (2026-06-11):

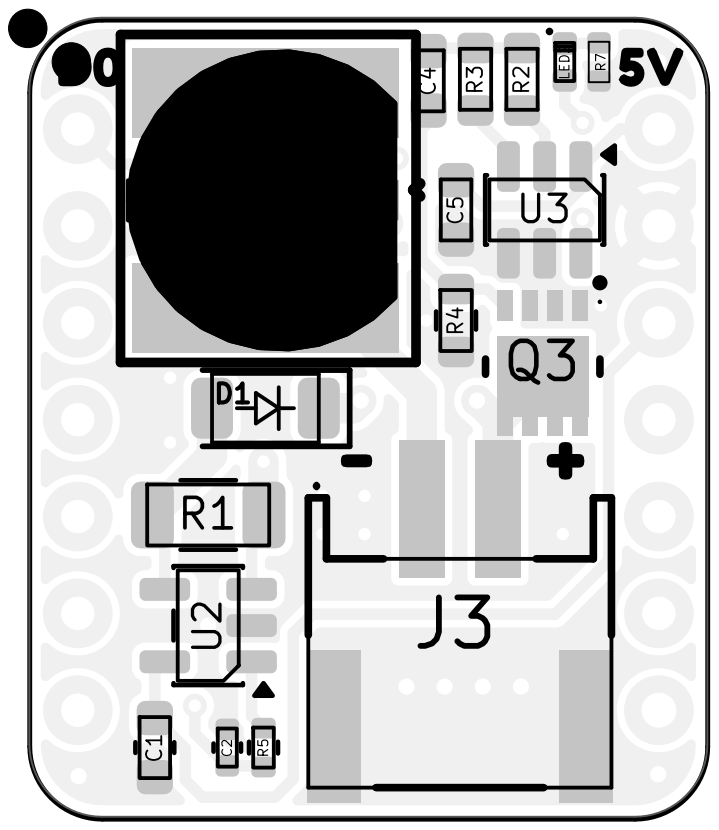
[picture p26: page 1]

Power Plane LLC
Sheet: Black And White TOP
D Date: 2026⁻04⁻15 KiCad E.D.A. 10.0.0
File: MistMaker⁻Seeed⁻Expansion⁻V0.1.kicad_pcb
Title: XiaoMistMaker

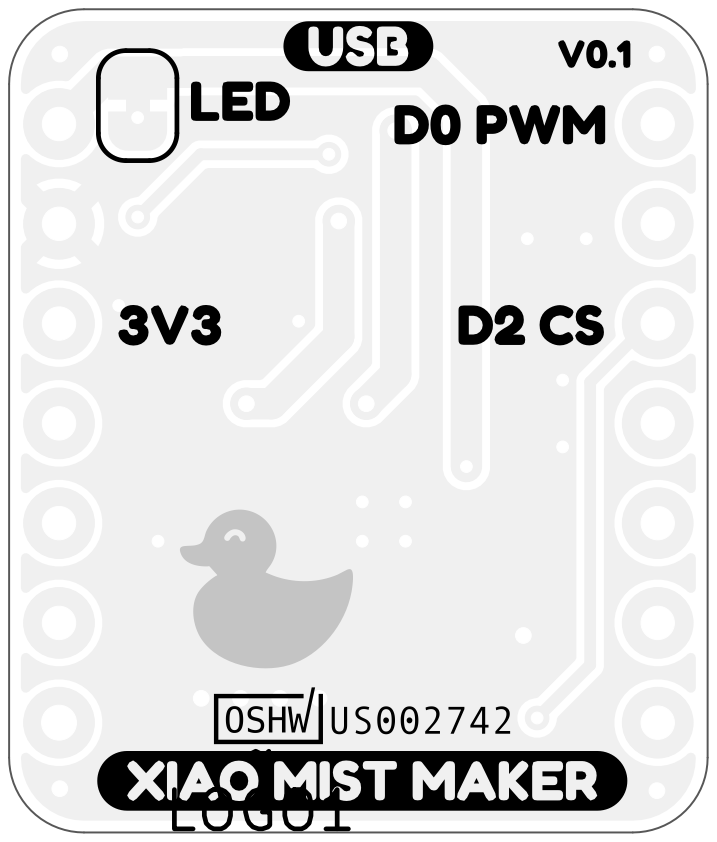
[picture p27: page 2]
~ LOGO1

Byproduct Lab XIAO Mist Maker By David Yang & shuang cai Board2Pdf: Black And White BOT - Page 2/4

Sheet: Black And White BOT Power Plane LLC

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

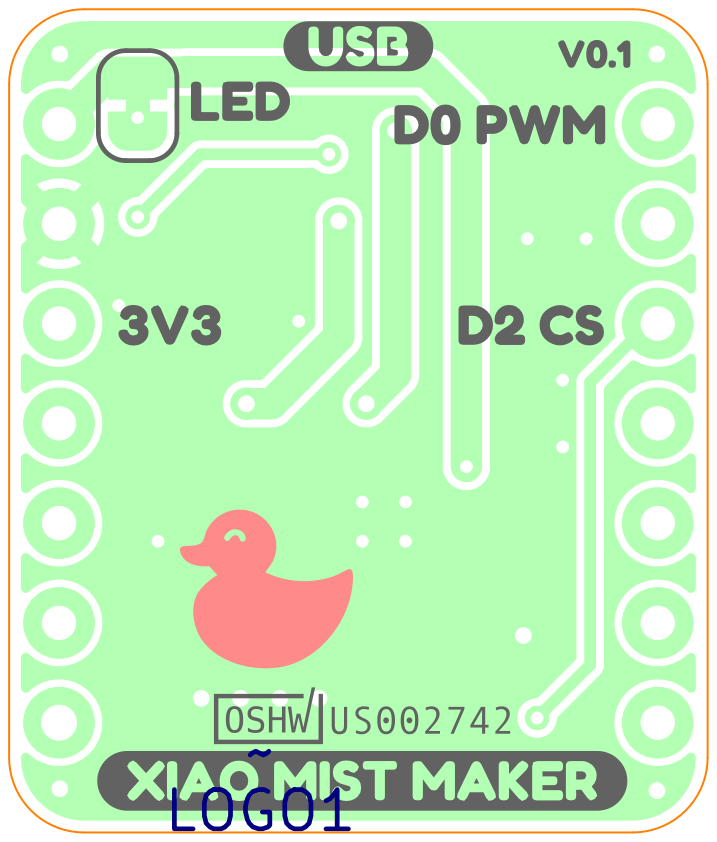
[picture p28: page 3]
~ LOGO1

Byproduct Lab XIAO Mist Maker By David Yang & shuang cai Board2Pdf: Colored BOT - Page 3/4

Sheet: Colored BOT Power Plane LLC

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

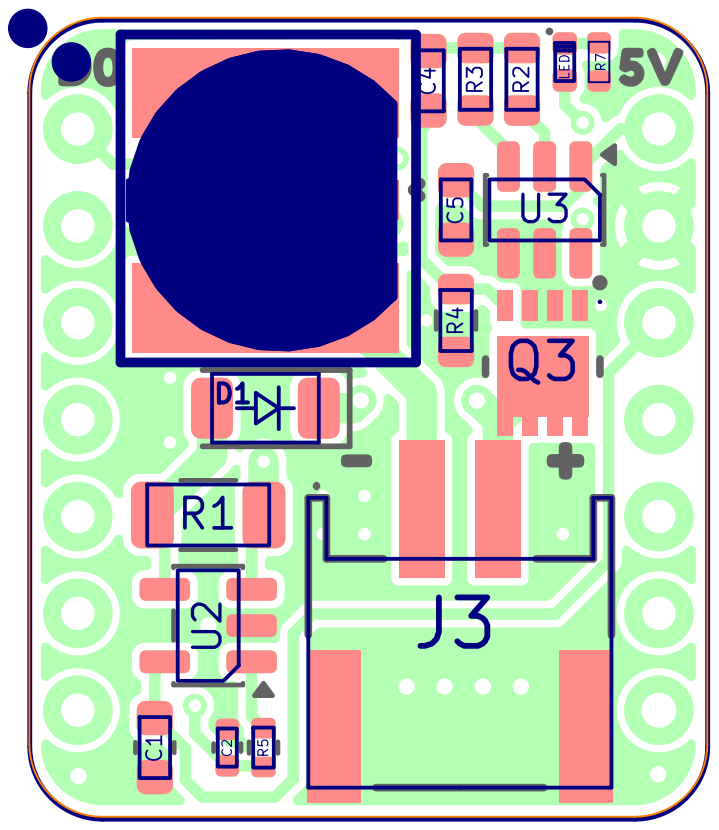
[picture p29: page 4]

Power Plane LLC
Sheet: Colored TOP
D Date: 2026⁻04⁻15 KiCad E.D.A. 10.0.0
File: MistMaker⁻Seeed⁻Expansion⁻V0.1.kicad_pcb
Title: XiaoMistMaker

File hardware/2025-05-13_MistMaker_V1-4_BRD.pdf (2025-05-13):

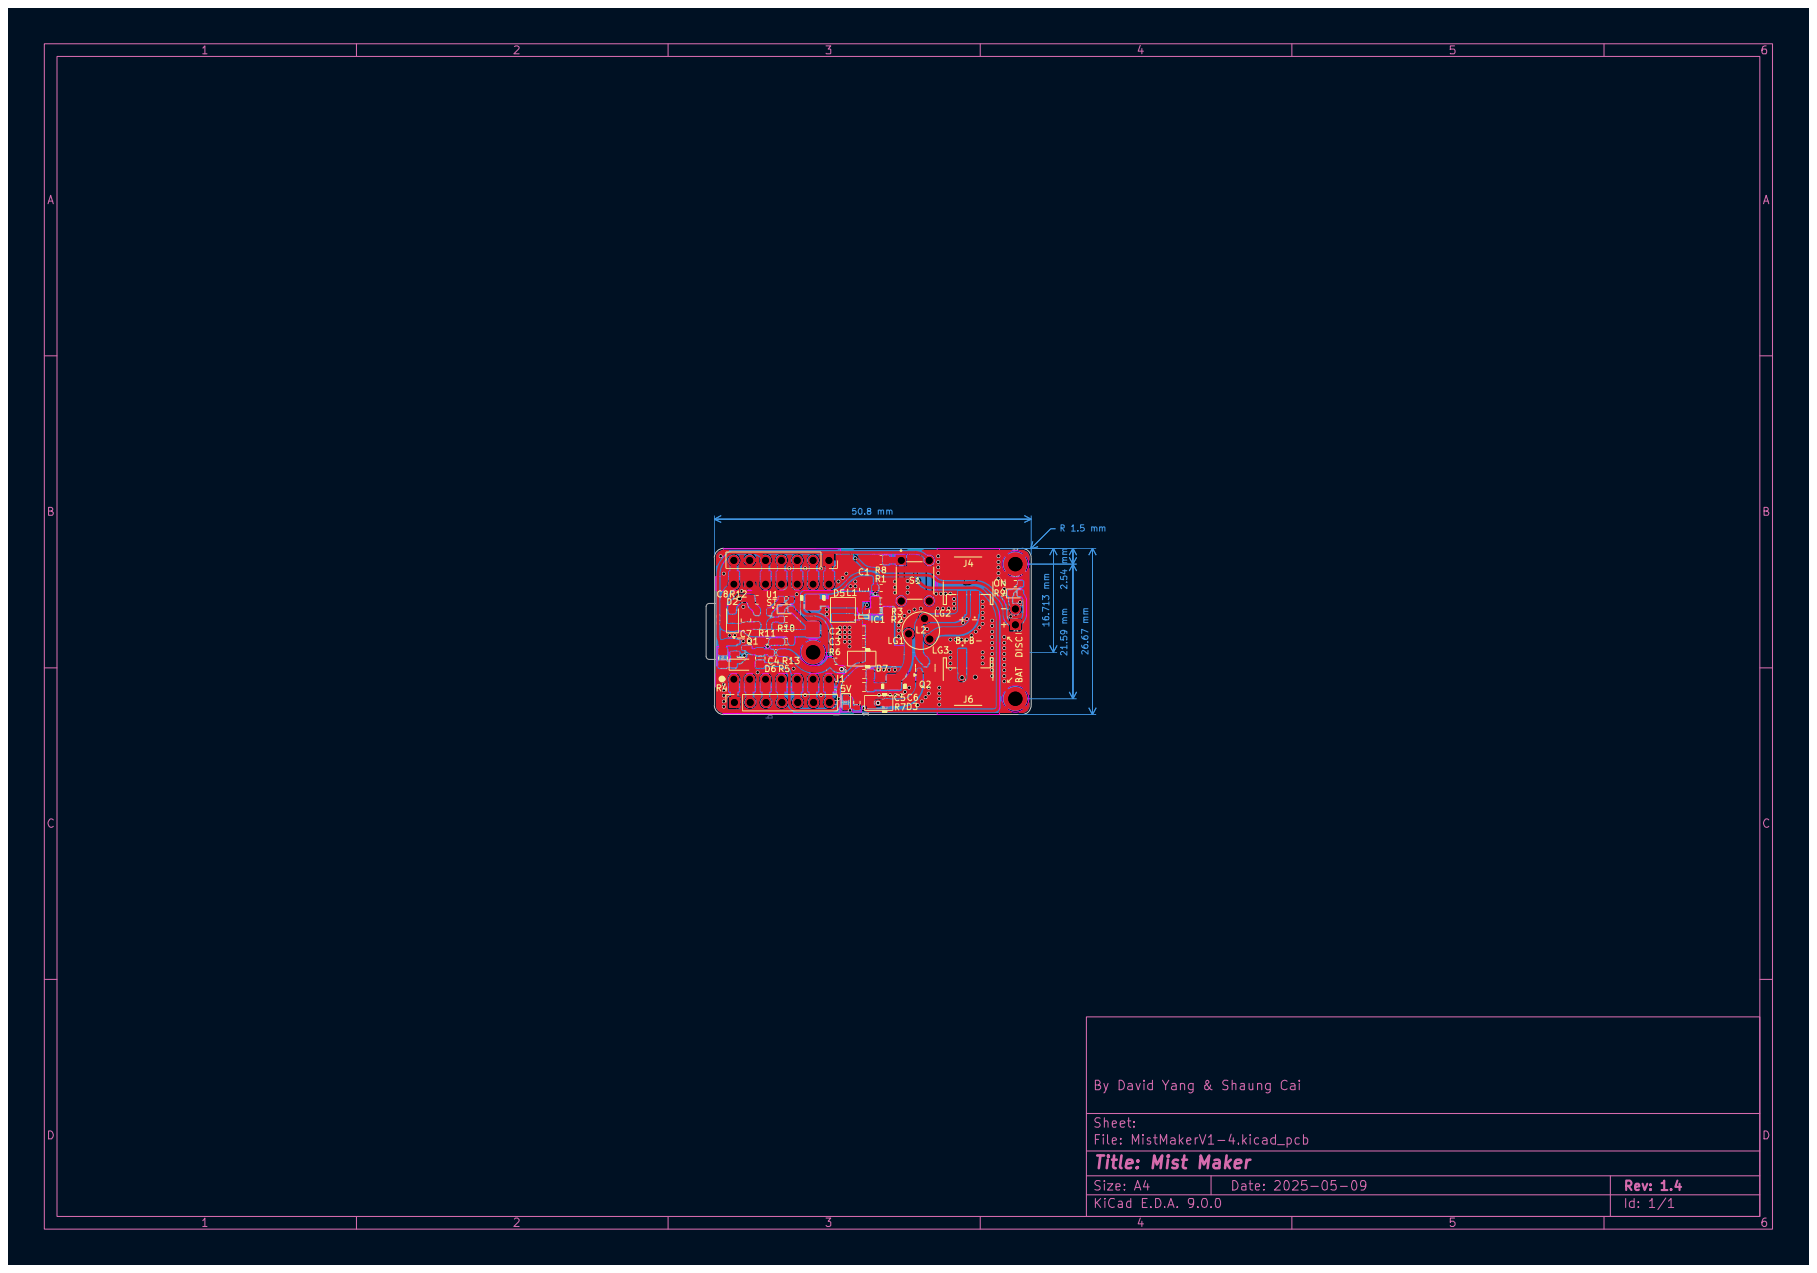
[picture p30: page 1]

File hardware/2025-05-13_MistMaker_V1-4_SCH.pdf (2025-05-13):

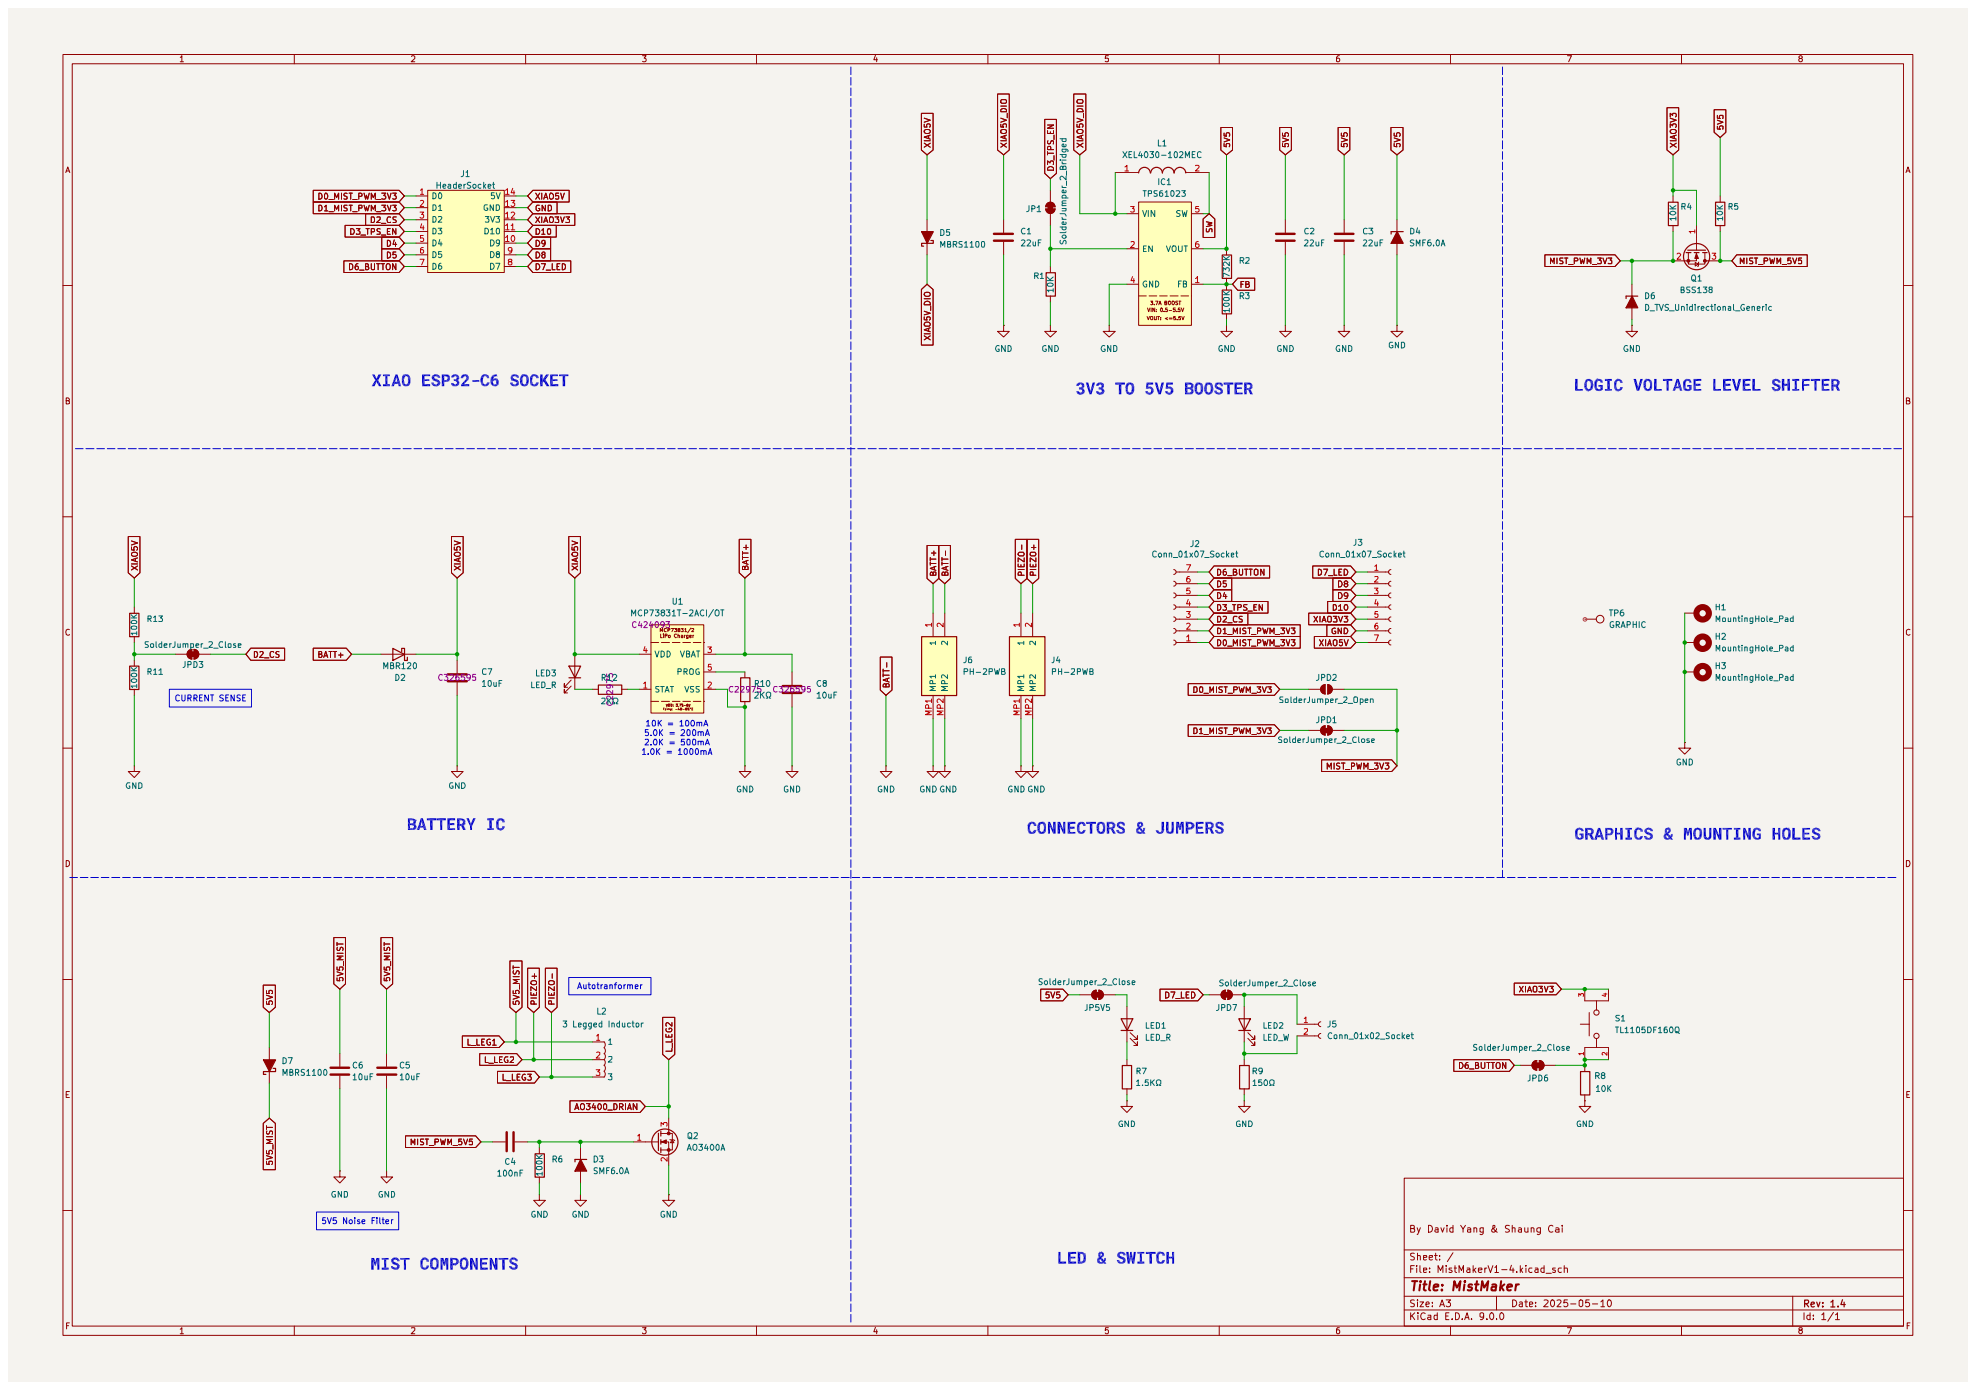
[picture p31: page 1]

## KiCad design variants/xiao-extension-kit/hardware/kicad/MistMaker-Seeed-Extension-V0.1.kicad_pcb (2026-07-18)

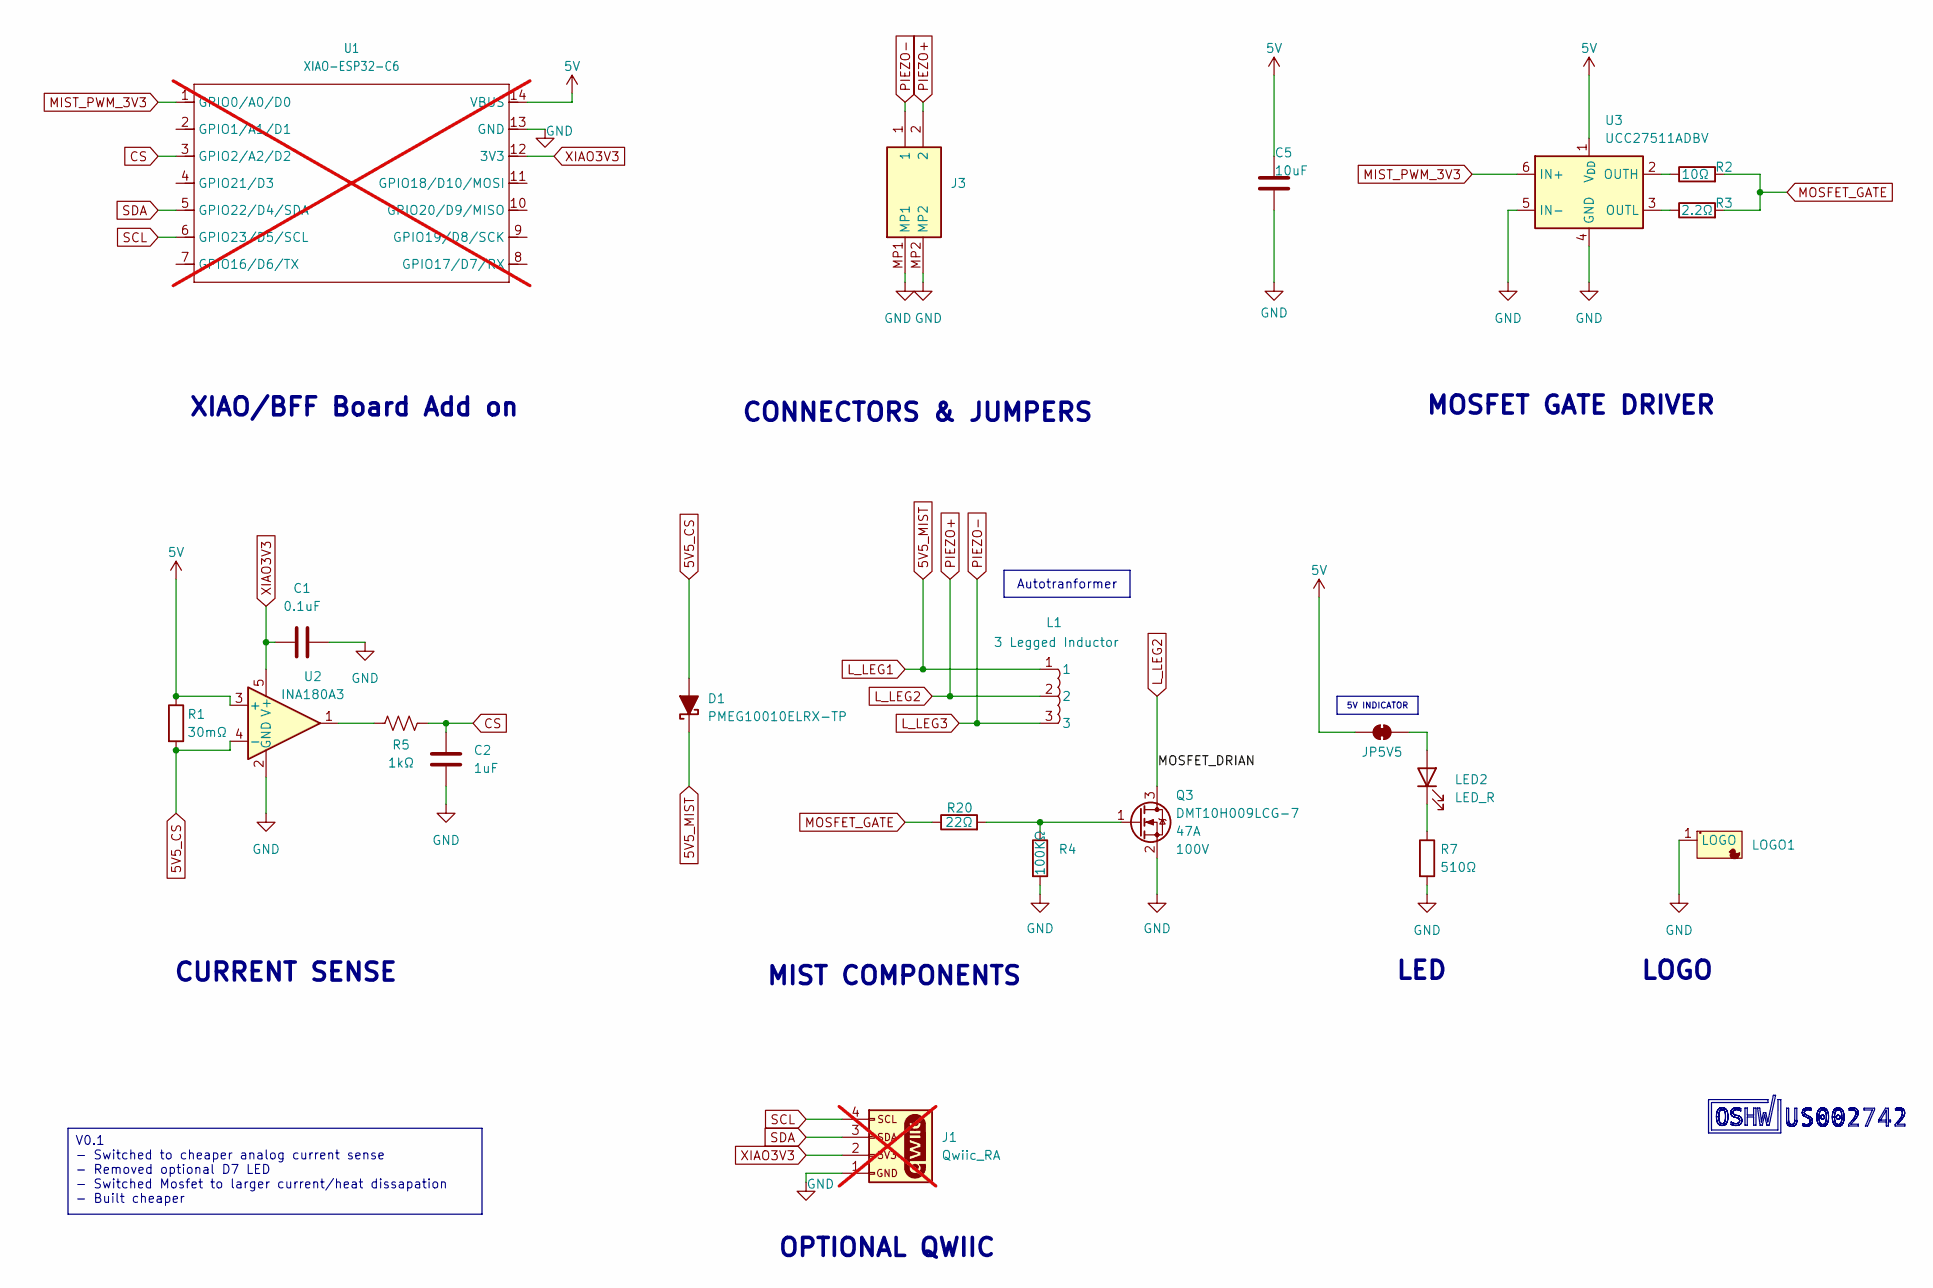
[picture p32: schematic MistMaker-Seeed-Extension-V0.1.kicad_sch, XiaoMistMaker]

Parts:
C1: 0.1uF; C_0603_1608Metric; LCSC C14663
C2: 1uF; C_0402_1005Metric; LCSC C14445
C5: 10uF; C_0402; LCSC C307415
D1: PMEG10010ELRX-TP; D_SOD-123FL; LCSC C7603319
J1: Qwiic_RA; JST_1x04_P1.0mm_Horizontal_SMD; not fitted
J3: PH-2PWB; PH2PWB; Manufacturer_Part_Number PH-2PWB; LCSC C2905019
JP5V5: SolderJumper_2_Close; SolderJumper-2_P1.3mm_Bridged_RoundedPad1.0x1.5mm
L1: 3 Legged Inductor; IND-SMD_3P-CD75; LCSC C49338546
LED2: LED_R; LED_0402_1005Metric; LCSC C25503345
LOGO1: DUCKY-LOGO
Q3: DMT10H009LCG-7; DMP3007SCG7; LCSC C461105
R1: 30mΩ; R_1206_3216Metric; LCSC C7467247
R2: 10Ω; R_0603; LCSC C22859
R3: 2.2Ω; R_0603; LCSC C22939
R4: 100KΩ; R_0603_1608Metric; JLC C14675
R5: 1kΩ; R_0402_1005Metric; LCSC C106235
R7: 510Ω; R_0402; LCSC C25123
R20: 22Ω; R_0402; LCSC C25092
U1: XIAO-ESP32-C6; XIAO-Add-On_No_Edge; not fitted
U2: INA180A3; SOT-23-5; LCSC C122882
U3: UCC27511ADBV; SOT-23-6; LCSC C2676982

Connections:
5V: C5.2, JP5V5.1 (A), R1.1, U1.14 (VBUS), U2.3 (+), U3.1 (V_{DD})
5V5_CS: D1.2 (A), R1.2, U2.4 (-)
5V5_MIST: D1.1 (K), L1.1
CS: C2.1, R5.1, U1.3 (GPIO2/A2/D2)
GND: C1.2, C2.2, C5.1, J1.1, J3.MP1, J3.MP2, LOGO1.1 (LOGO_1), Q3.2 (S), R4.2, R7.2, U1.13 (GND), U2.2 (GND), U3.4 (GND), U3.5 (IN-)
L_LEG2: J3.2, L1.2, Q3.3 (D)
L_LEG3: J3.1, L1.3
MIST_PWM_3V3: U1.1 (GPIO0/A0/D0), U3.6 (IN+)
MOSFET_GATE: R2.2, R3.2, R20.1
unnamed: JP5V5.2 (B), LED2.2 (A)
unnamed: LED2.1 (K), R7.1
unnamed: Q3.1 (G), R4.1, R20.2
unnamed: R5.2, U2.1
unnamed: R2.1, U3.2 (OUTH)
unnamed: R3.1, U3.3 (OUTL)
SCL: J1.4, U1.6 (GPIO23/D5/SCL)
SDA: J1.3, U1.5 (GPIO22/D4/SDA)
XIAO3V3: C1.1, J1.2, U1.12 (3V3), U2.5 (V+)

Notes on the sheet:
LED
XIAO/BFF Board Add on
MOSFET GATE DRIVER
CURRENT SENSE
MIST COMPONENTS
OPTIONAL QWIIC
LOGO
CONNECTORS & JUMPERS
5V INDICATOR
V0.1 - Switched to cheaper analog current sense - Removed optional D7 LED - Switched Mosfet to larger current/heat dissapation - Built cheaper
Autotranformer

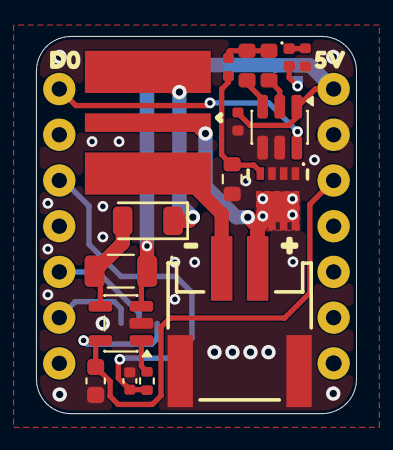
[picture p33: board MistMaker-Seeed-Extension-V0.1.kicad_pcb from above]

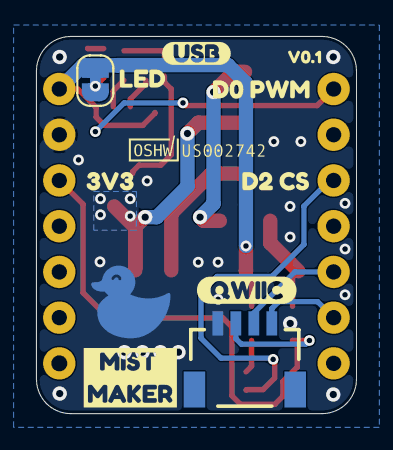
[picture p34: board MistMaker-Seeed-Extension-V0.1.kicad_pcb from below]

Board: 2 copper layers, 17.8 x 21.0 mm, 33 parts (11 on the bottom side), 18 nets.

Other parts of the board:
kibuzzard-6A26391D: G***; kibuzzard-6A26391D
kibuzzard-6A263943: G***; kibuzzard-6A263943
kibuzzard-69A01650: G***; kibuzzard-69A01650
kibuzzard-69A01793: G***; kibuzzard-69A01793
kibuzzard-69DEF6AD: G***; kibuzzard-69DEF6AD
kibuzzard-69DEF161: G***; kibuzzard-69DEF161
kibuzzard-698C1293: G***; kibuzzard-698C1293
kibuzzard-698C1416: G***; kibuzzard-698C1416
kibuzzard-698C1426: G***; kibuzzard-698C1426
kibuzzard-6989FB09: G***; kibuzzard-6989FB09
kibuzzard-6989FFC2: G***; kibuzzard-6989FFC2
kibuzzard-6989FFFB: G***; kibuzzard-6989FFFB

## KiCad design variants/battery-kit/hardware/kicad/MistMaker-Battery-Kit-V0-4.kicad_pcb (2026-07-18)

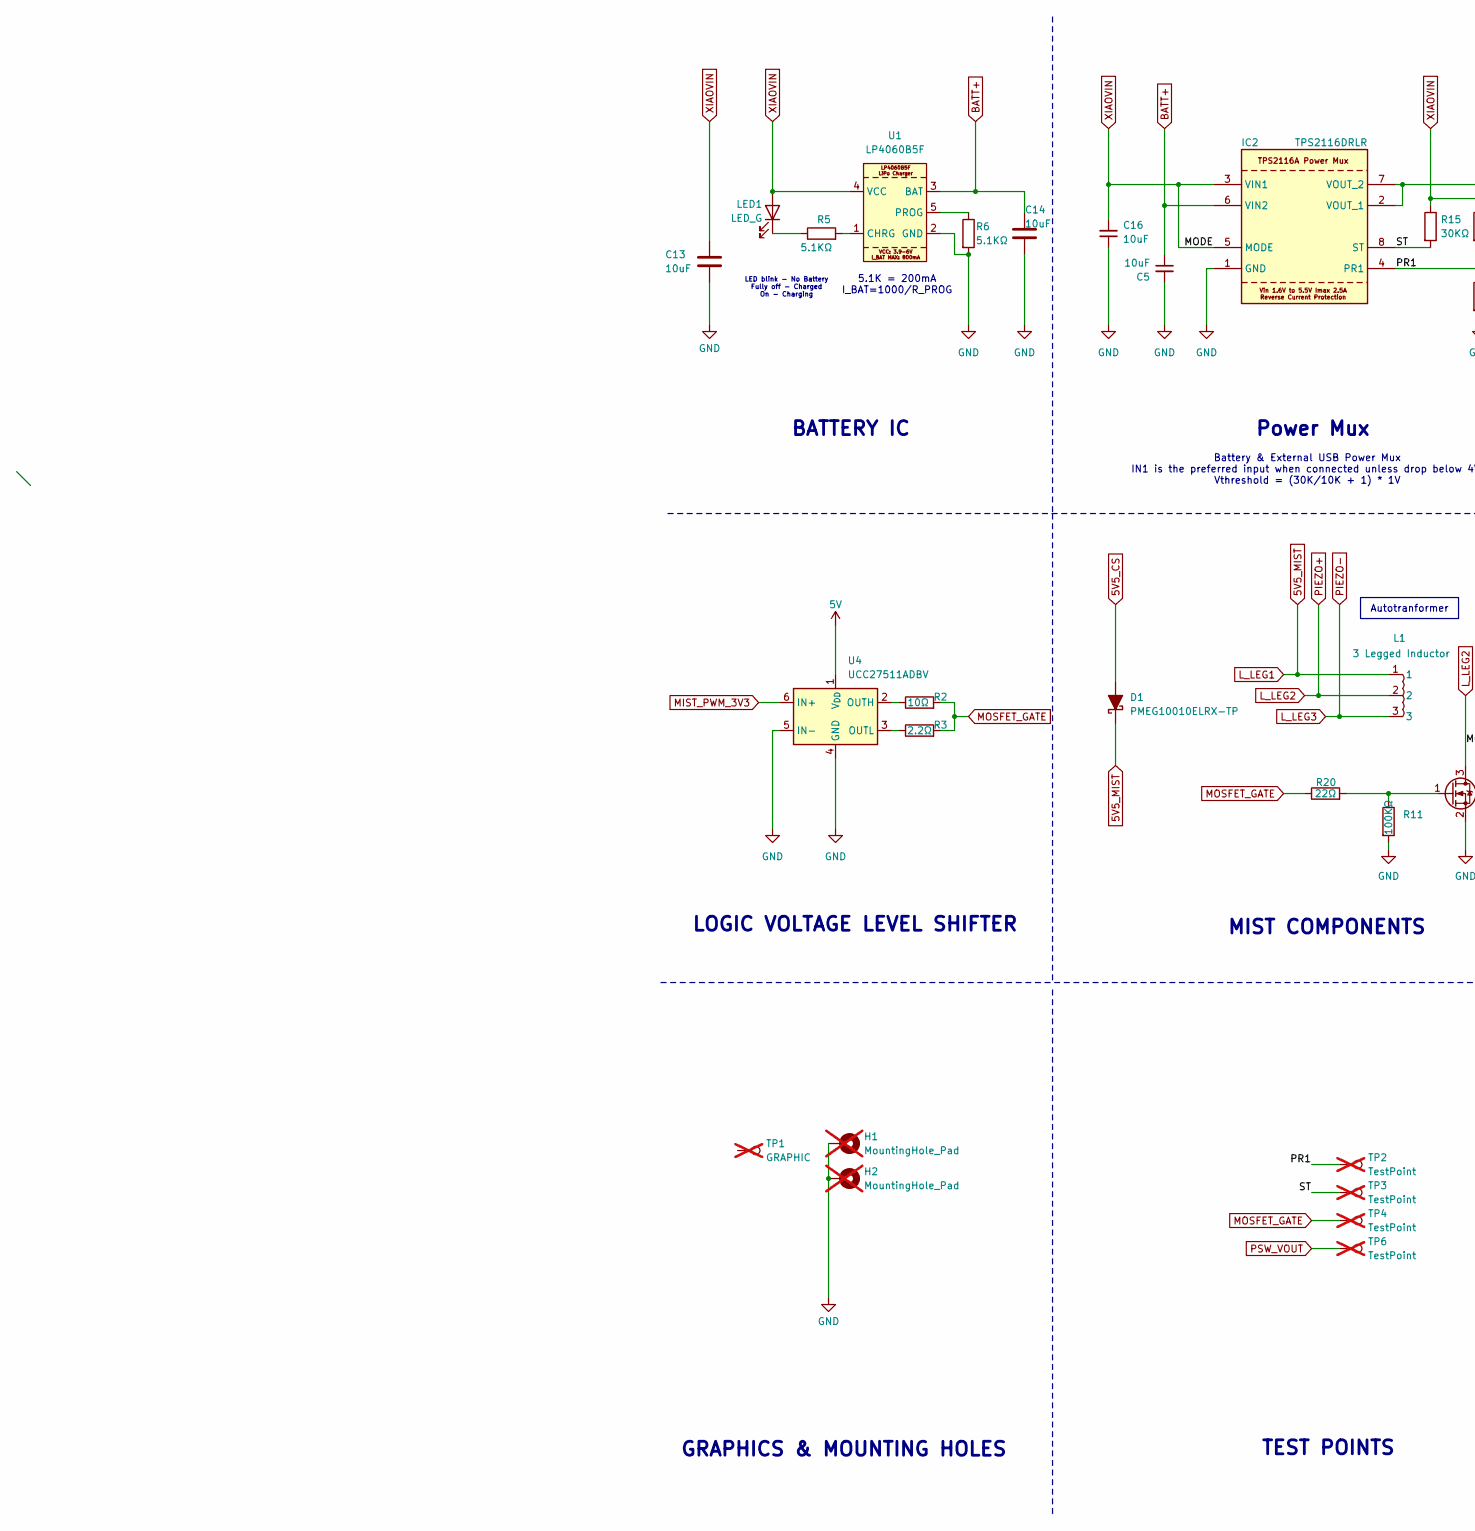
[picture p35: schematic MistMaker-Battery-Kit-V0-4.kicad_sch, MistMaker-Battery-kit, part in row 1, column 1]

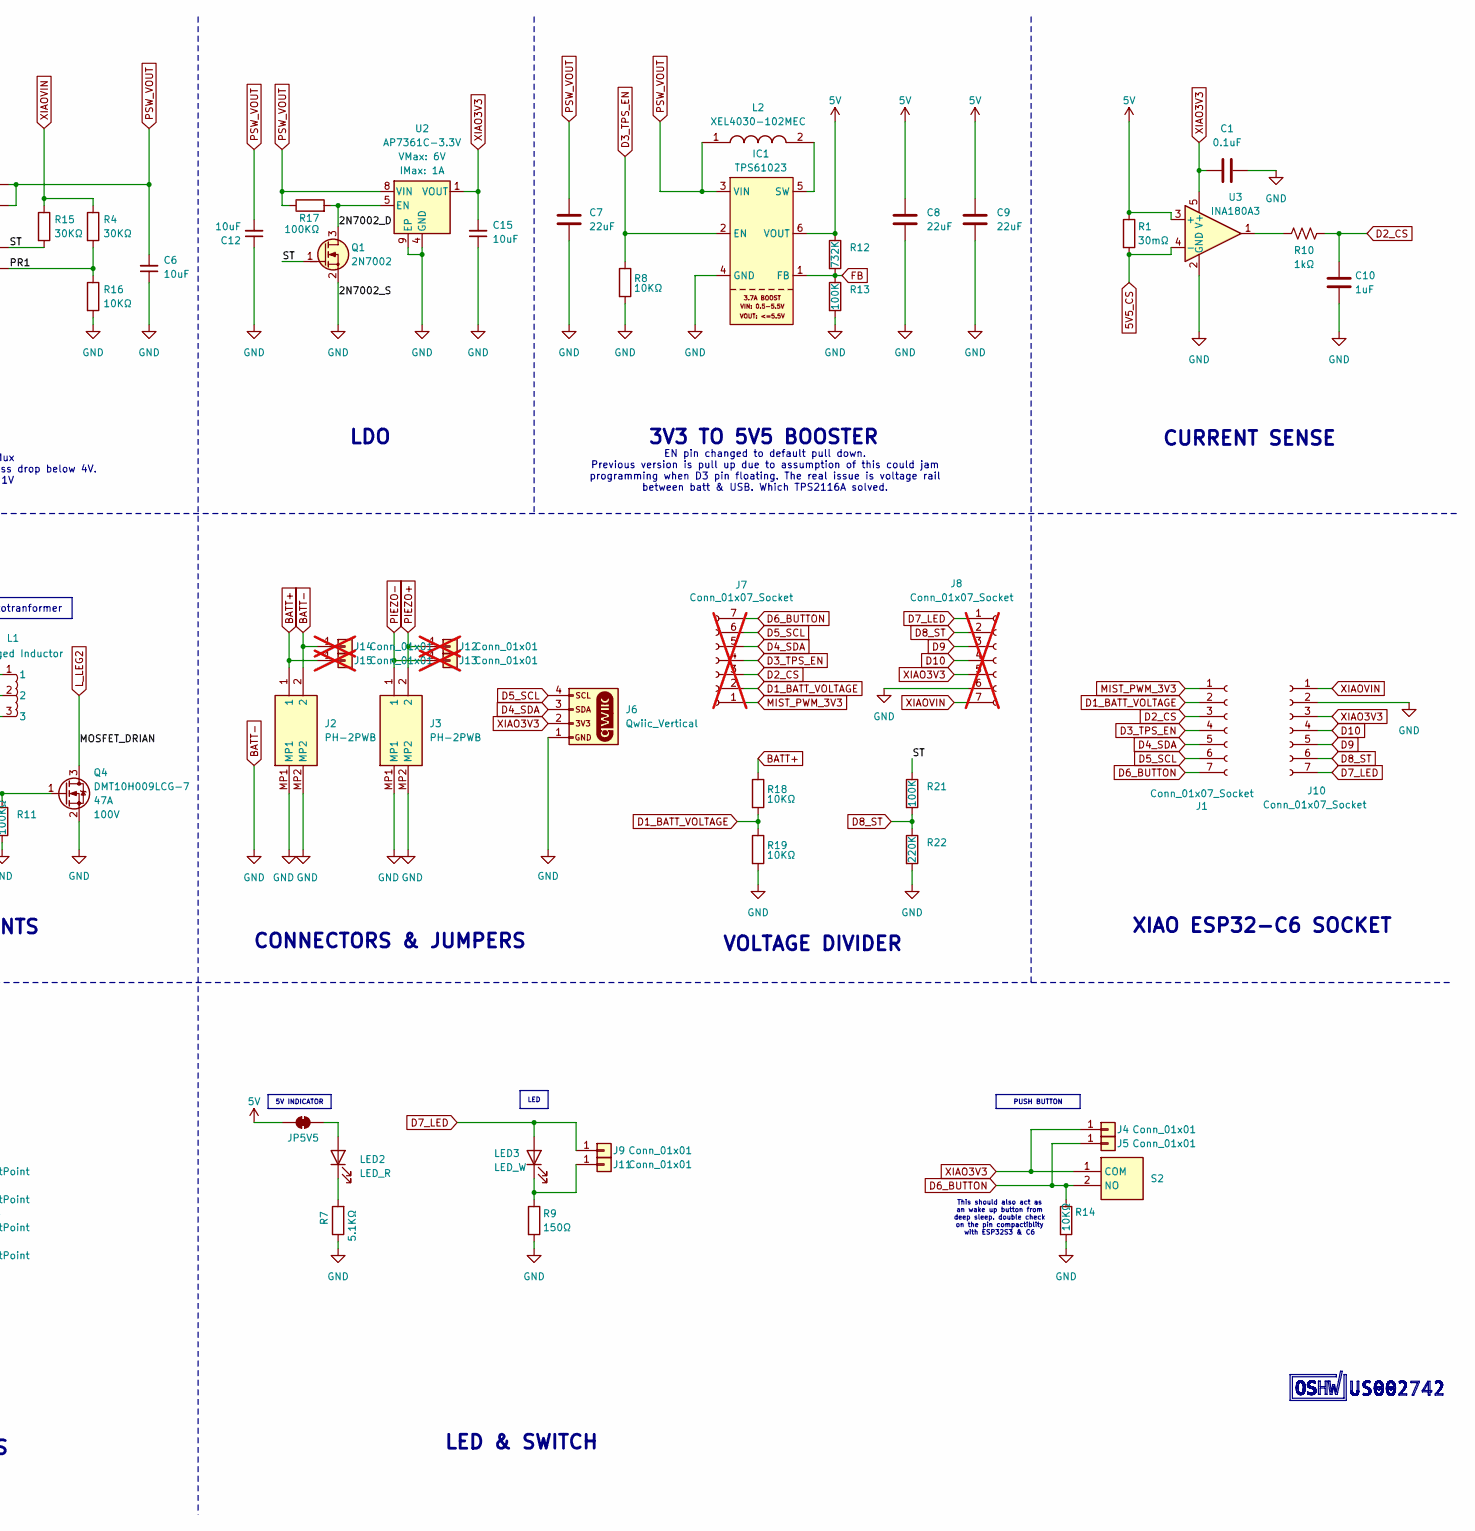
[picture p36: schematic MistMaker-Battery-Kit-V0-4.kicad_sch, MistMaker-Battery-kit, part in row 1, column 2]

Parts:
C1: 0.1uF; C_0603_1608Metric; LCSC C14663
C5, C6, C12, C15, C16: 10uF; C_0603; LCSC C96446
C7, C8, C9: 22uF; C_0805_2012Metric_Pad1.18x1.45mm_HandSolder; LCSC C98190
C10: 1uF; C_0402_1005Metric; LCSC C14445
C13, C14: 10uF; C_0402; LCSC C307415
D1: PMEG10010ELRX-TP; D_SOD-123FL; LCSC C7603319
H1, H2: MountingHole_Pad; MountingHole_2.7mm_M2.5_ISO7380_Pad_SmallerPad; not fitted
IC1: TPS61023; SOT-563; LCSC C919459
IC2: TPS2116DRLR; TPS62932DRLR; Manufacturer_Part_Number TPS2116DRLR; Mouser Part Number 595-TPS2116DRLR
J1, J10: Conn_01x07_Socket; PinSocket_1x07_P2.54mm_Vertical_MiniSilk; LCSC C27985232
J2, J3: PH-2PWB; PH2PWB; Manufacturer_Part_Number PH-2PWB; LCSC C2905019
J4, J5, J9, J11: Conn_01x01; SolderWirePad_1x01_SMD_1x2mm
J6: Qwiic_Vertical; JST_1x04_P1.0mm_Vertical_SMD; LCSC C2845372
J7, J8: Conn_01x07_Socket; PinSocket_1x07_P2.54mm_Vertical; not fitted
J12, J13, J14, J15: Conn_01x01; SolderWirePad_1x01_SMD_1x2mm; not fitted
JP5V5: SolderJumper_2_Close; SolderJumper-2_P1.3mm_Bridged_RoundedPad1.0x1.5mm
L1: 3 Legged Inductor; IND-SMD_3P-CD75; LCSC C49338546
L2: XEL4030-102MEC; XEL4030102MEC; Manufacturer_Part_Number XEL4030-102MEC; Mouser Part Number 994-XEL4030-102MEC
LED1: LED_G; LED_0402_1005Metric; LCSC C965793
LED2: LED_R; LED_0402_1005Metric; LCSC C25503345
LED3: LED_W; LED_0402_1005Metric; LCSC C51933306
Q1: 2N7002; SOT-23; LCSC C8545
Q4: DMT10H009LCG-7; DMP3007SCG7; LCSC C461105
R1: 30mΩ; R_1206_3216Metric; LCSC C7467247
R2: 10Ω; R_0603; LCSC C22859
R3: 2.2Ω; R_0603; LCSC C22939
R4, R15: 30KΩ; R_0402; LCSC C138008
R5, R6, R7: 5.1KΩ; R_0402; LCSC C25905
R8, R14, R16, R18, R19: 10KΩ; R_0402; LCSC C25744
R9: 150Ω; R_0402; LCSC C25082
R10: 1kΩ; R_0402_1005Metric; LCSC C106235
R11, R17: 100KΩ; R_0603_1608Metric; LCSC C14675
R12: 732K; R_0402; LCSC C137940
R13, R21: 100K; R_0402; LCSC C25741
R20: 22Ω; R_0402; LCSC C25092
R22: 220K; R_0402; LCSC C2909335
S2: TS-1088-AR02016; TS1088AR02016; Manufacturer_Part_Number TS-1088-AR02016; LCSC C720477
TP1: GRAPHIC; DUCKY_ICON_S; not fitted
TP2, TP3, TP4, TP6: TestPoint; TestPoint-1.0mm; not fitted
U1: LP4060B5F; BATT_Charger_SOT-23-5_Min_Silk; LCSC C517259
U2: AP7361C-3.3V; DFN-8_3x3mm_P0.65mm_EP2.25x1.5mm; LCSC C151007
U3: INA180A3; SOT-23-5; LCSC C122882
U4: UCC27511ADBV; SOT-23-6; LCSC C2676982

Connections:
5V: C8.1, C9.1, IC1.6 (VOUT), JP5V5.1 (A), R1.1, R12.1, U3.3 (+), U4.1 (V_{DD})
5V5_CS: D1.2 (A), R1.2, U3.4 (-)
5V5_MIST: D1.1 (K), L1.1
/2N7002_D: Q1.3 (D), R17.2, U2.5 (EN)
/PR1: IC2.4 (PR1), R4.2, R16.1, TP2.1 (1_1)
/ST: IC2.8 (ST), Q1.1 (G), R15.2, R21.1, TP3.1 (1_1)
BATT+: C5.1, C14.2, IC2.6 (VIN2), J2.1, J15.1 (Pin_1_1), R18.1, U1.3 (BAT)
BATT-: C1.2, C5.2, C6.1, C7.2, C8.2, C9.2, C10.2, C12.1, C13.2, C14.1, C15.1, C16.1, H1.1 (1_1), H2.1 (1_1), IC1.4 (GND), IC2.1 (GND), J2.2, J2.MP1, J2.MP2, J3.MP1, J3.MP2, J6.1, J8.6, J10.2, J14.1 (Pin_1_1), Q1.2 (S), Q4.2 (S), R6.2, R7.1, R8.2, R9.2, R11.2, R13.2, R14.2, R16.2, R19.2, R22.2, U1.2 (GND), U2.4 (GND), U2.9 (EP), U3.2 (GND), U4.4 (GND), U4.5 (IN-)
D1_BATT_VOLTAGE: J1.2, J7.2, R18.2, R19.1
D2_CS: C10.1, J1.3, J7.3, R10.1
D3_TPS_EN: IC1.2 (EN), J1.4, J7.4, R8.1
D4_SDA: J1.5, J6.3, J7.5
D5_SCL: J1.6, J6.4, J7.6
D6_BUTTON: J1.7, J5.1 (Pin_1_1), J7.7, R14.1, S2.2 (NO)
D7_LED: J8.1, J9.1 (Pin_1_1), J10.7, LED3.2 (A)
D8_ST: J8.2, J10.6, R21.2, R22.1
D9: J8.3, J10.5
D10: J8.4, J10.4
FB: IC1.1 (FB), R12.2, R13.1
L_LEG2: J3.2, J12.1 (Pin_1_1), L1.2, Q4.3 (D)
L_LEG3: J3.1, J13.1 (Pin_1_1), L1.3
MIST_PWM_3V3: J1.1, J7.1, U4.6 (IN+)
MOSFET_GATE: R2.2, R3.2, R20.1, TP4.1 (1_1)
unnamed: IC1.5 (SW), L2.2
unnamed: J11.1 (Pin_1_1), LED3.1 (K), R9.1
unnamed: JP5V5.2 (B), LED2.2 (A)
unnamed: LED1.1 (K), R5.1
unnamed: LED2.1 (K), R7.2
unnamed: Q4.1 (G), R11.1, R20.2
unnamed: R10.2, U3.1
unnamed: R5.2, U1.1 (CHRG)
unnamed: R6.1, U1.5 (PROG)
unnamed: R2.1, U4.2 (OUTH)
unnamed: R3.1, U4.3 (OUTL)
PSW_VOUT: C6.2, C7.1, C12.2, IC1.3 (VIN), IC2.2 (VOUT_1), IC2.7 (VOUT_2), L2.1, R17.1, TP6.1 (1_1), U2.8 (VIN)
XIAO3V3: C1.1, C15.2, J4.1 (Pin_1_1), J6.2, J8.5, J10.3, S2.1 (COM), U2.1 (VOUT), U3.5 (V+)
XIAOVIN: C13.1, C16.2, IC2.3 (VIN1), IC2.5 (MODE), J8.7, J10.1, LED1.2 (A), R4.1, R15.1, U1.4 (VCC)

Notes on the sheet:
GRAPHICS & MOUNTING HOLES
VOLTAGE DIVIDER
CONNECTORS & JUMPERS
Battery & External USB Power Mux IN1 is the preferred input when connected unless drop below 4V. Vthreshold = (30K/10K + 1) * 1V
CURRENT SENSE
Power Mux
BATTERY IC
TEST POINTS
5.1K = 200mA I_BAT=1000/R_PROG
LDO
XIAO ESP32-C6 SOCKET
LED & SWITCH
EN pin changed to default pull down. Previous version is pull up due to assumption of this could jam programming when D3 pin floating. The real issue is voltage rail between batt & USB. Which TPS2116A solved.
LOGIC VOLTAGE LEVEL SHIFTER
3V3 TO 5V5 BOOSTER
MIST COMPONENTS
PUSH BUTTON
Autotranformer
LED blink - No Battery Fully off - Charged On - Charging
This should also act as an wake up button from deep sleep. double check on the pin compactiblity with ESP32S3 & C6
LED
5V INDICATOR

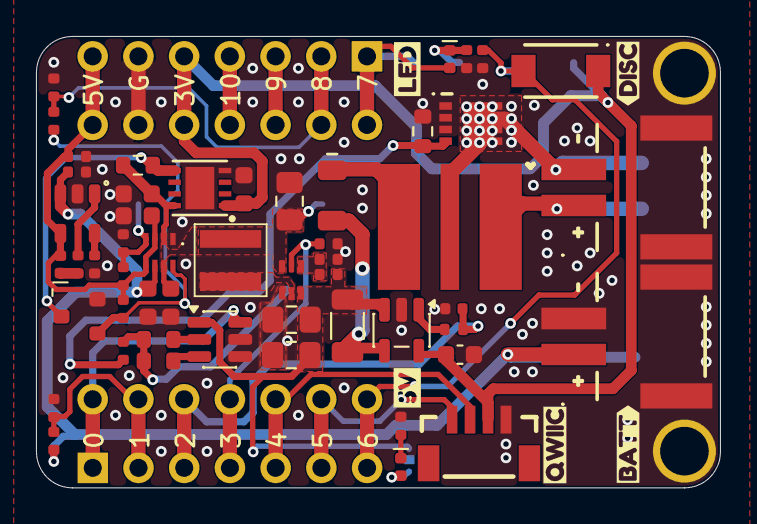
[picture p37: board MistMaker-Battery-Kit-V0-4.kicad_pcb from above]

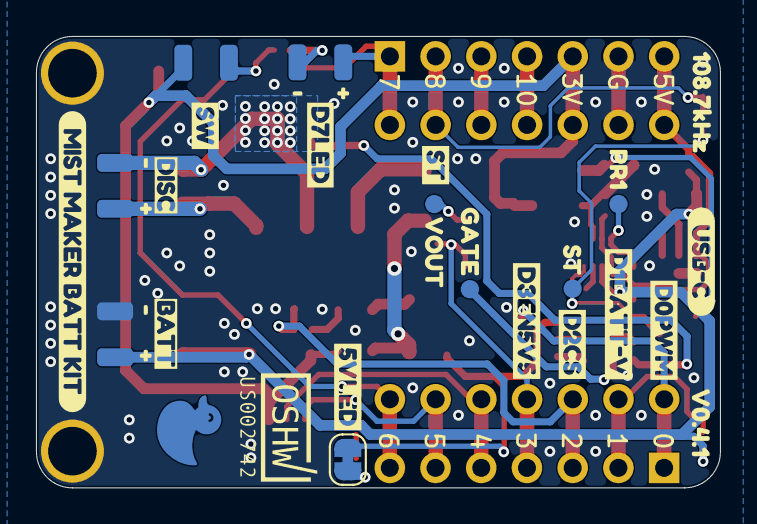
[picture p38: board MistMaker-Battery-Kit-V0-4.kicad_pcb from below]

Board: 2 copper layers, 38.0 x 25.1 mm, 105 parts (38 on the bottom side), 37 nets.

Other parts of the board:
kibuzzard-6A2F79F4: G***; kibuzzard-6A2F79F4
kibuzzard-6A38CD61: G***; kibuzzard-6A38CD61
kibuzzard-6A316FBE: G***; kibuzzard-6A316FBE
kibuzzard-6A317060: G***; kibuzzard-6A317060
kibuzzard-6A488614: G***; kibuzzard-6A488614
kibuzzard-69DF3D6E: G***; kibuzzard-69DF3D6E
kibuzzard-69DF3D93: G***; kibuzzard-69DF3D93
kibuzzard-69DF40D0: G***; kibuzzard-69DF40D0
kibuzzard-69DF40F6: G***; kibuzzard-69DF40F6
kibuzzard-69DF44F0, kibuzzard-69DF44F0#2: G***; kibuzzard-69DF44F0
kibuzzard-69DF407A: G***; kibuzzard-69DF407A
kibuzzard-69DF414F: G***; kibuzzard-69DF414F
kibuzzard-69DF4510, kibuzzard-69DF4510#2: G***; kibuzzard-69DF4510
kibuzzard-69E03B47: G***; kibuzzard-69E03B47
kibuzzard-69EB8B1C: G***; kibuzzard-69EB8B1C
kibuzzard-69EB8B4D: G***; kibuzzard-69EB8B4D
kibuzzard-69EB8D01: G***; kibuzzard-69EB8D01
kibuzzard-69EB47E7: G***; kibuzzard-69EB47E7
kibuzzard-69EB84CC: G***; kibuzzard-69EB84CC
kibuzzard-69EB87CA: G***; kibuzzard-69EB87CA
kibuzzard-69EB87F5: G***; kibuzzard-69EB87F5
kibuzzard-69EB470E: G***; kibuzzard-69EB470E
kibuzzard-69EB898A, kibuzzard-69EB898A#2, kibuzzard-69EB898A#3: G***; kibuzzard-69EB898A
kibuzzard-69EB4726: G***; kibuzzard-69EB4726
kibuzzard-69EB8824: G***; kibuzzard-69EB8824
kibuzzard-69EB8840: G***; kibuzzard-69EB8840
kibuzzard-69EB8976, kibuzzard-69EB8976#2, kibuzzard-69EB8976#3: G***; kibuzzard-69EB8976

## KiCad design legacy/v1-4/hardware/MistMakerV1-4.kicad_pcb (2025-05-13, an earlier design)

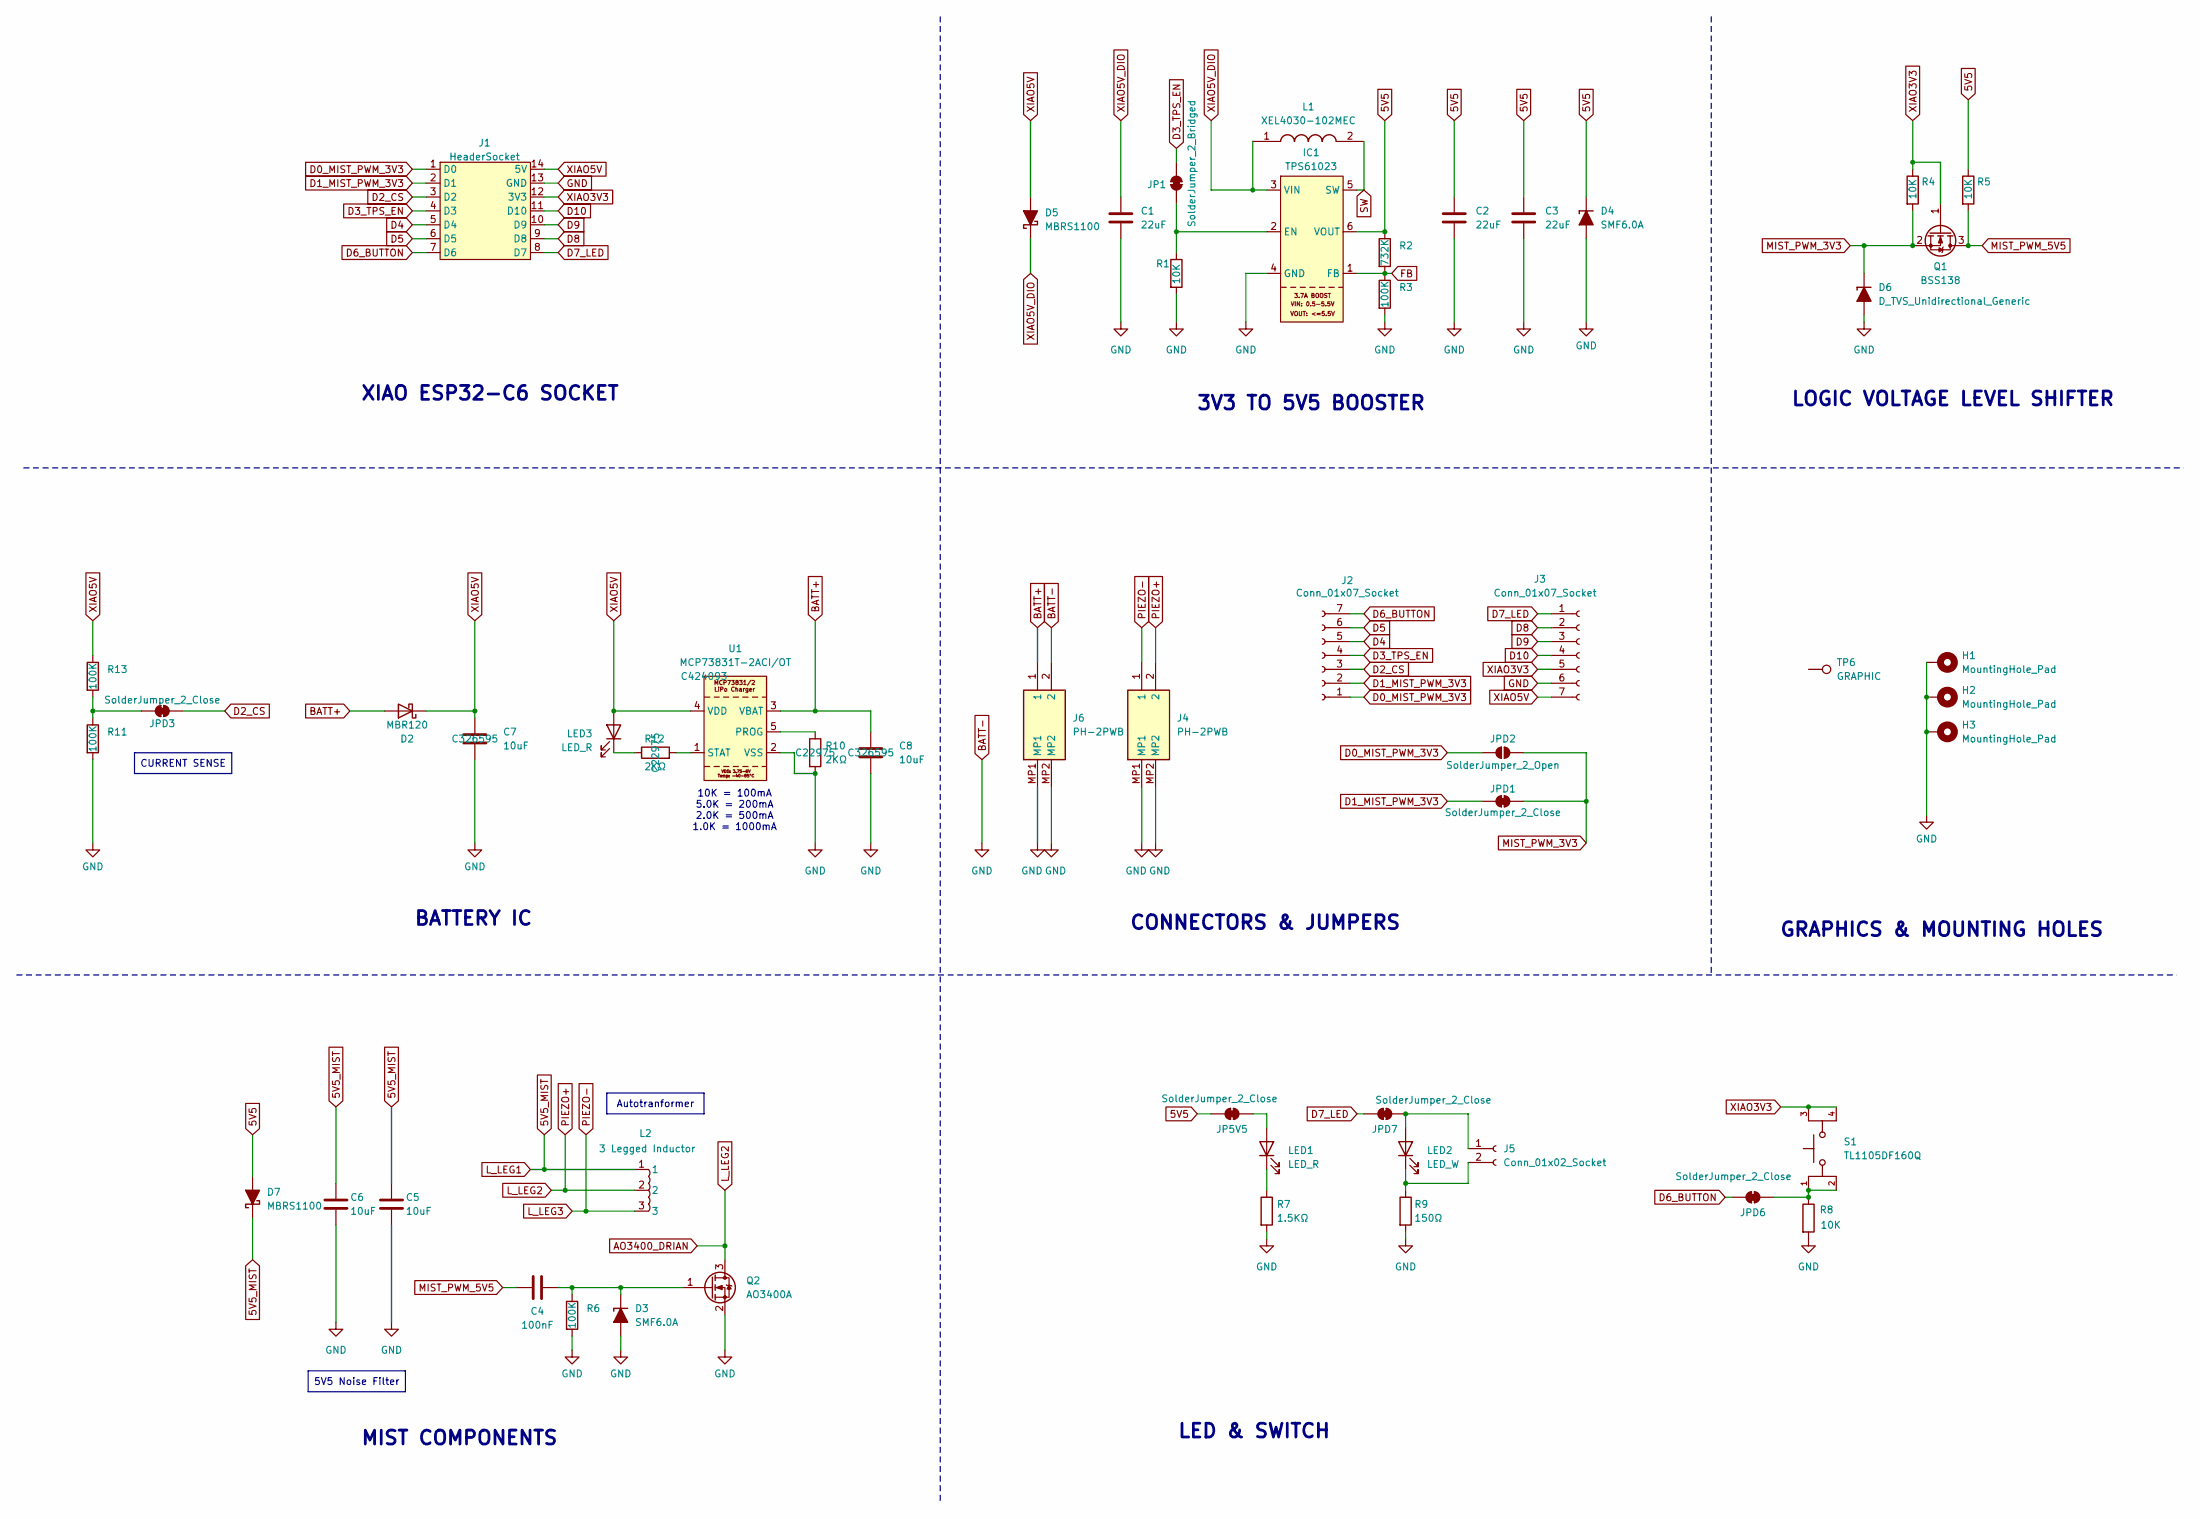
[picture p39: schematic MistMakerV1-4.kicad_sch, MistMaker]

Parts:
C1, C2, C3: 22uF; C_0805_2012Metric_Pad1.18x1.45mm_HandSolder; JLC C98190
C4: 100nF; C_0603_1608Metric; JLC C3011705
C5, C6: 10uF; C_0805_2012Metric_Pad1.18x1.45mm_HandSolder; JLC C326595
C7, C8: 10uF; C_0805_2012Metric; JLC C326595
D2: MBR120; D_SOD-123F; JLC C81143
D3, D4: SMF6.0A; D_SOD-123F; JLC C19077499
D5, D7: MBRS1100; D_SMB_Min_Silk; JLC C82068
D6: D_TVS_Unidirectional_Generic; D_SOD-323_HandSoldering; JLC C20617916
H1, H2, H3: MountingHole_Pad; MountingHole_2.2mm_M2_DIN965_Pad
IC1: TPS61023; SOTFL50P160X60-6N; JLC C919459
J1: HeaderSocket; XIAO-ESP32C6-DIP
J2, J3: Conn_01x07_Socket; PinSocket_1x07_P2.54mm_Vertical
J4, J6: PH-2PWB; PH2PWB; Manufacturer_Part_Number PH-2PWB; JLC C2905019
J5: Conn_01x02_Socket; PinHeader_1x02_P2.54mm_less_Marks
JP1: SolderJumper_2_Bridged; SolderJumper-2_P1.3mm_Bridged_RoundedPad1.0x1.5mm
JP5V5: SolderJumper_2_Close; SolderJumper-2_P1.3mm_Bridged_RoundedPad1.0x1.5mm
JPD1, JPD3, JPD6, JPD7: SolderJumper_2_Close; SolderJumper-2_P1.3mm_Bridged_RoundedPad1.0x1.5mm
JPD2: SolderJumper_2_Open; SolderJumper-2_P1.3mm_Open_RoundedPad1.0x1.5mm
L1: XEL4030-102MEC; XEL4030102MEC; Manufacturer_Part_Number XEL4030-102MEC; Mouser Part Number 994-XEL4030-102MEC
L2: 3 Legged Inductor; 3_Leg_Autotransformer
LED1, LED3: LED_R; LED_0603_1608Metric; JLC C2286
LED2: LED_W; LED_0603_1608Metric; JLC C2290
Q1: BSS138; SOT-23; JLC C40912
Q2: AO3400A; SOT-23; JLC C20917
R1: 10K; R_0603_1608Metric_Pad0.98x0.95mm_HandSolder; JLC C98220
R2: 732K; R_0603_1608Metric_Pad0.98x0.95mm_HandSolder; JLC C246003
R3: 100K; R_0603_1608Metric_Pad0.98x0.95mm_HandSolder; JLC C14675
R4, R5: 10K; R_0805_2012Metric_Pad1.20x1.40mm_HandSolder; JLC C17414
R6, R11, R13: 100K; R_0603_1608Metric; JLC C14675
R7: 1.5KΩ; R_0603_1608Metric; JLC C114668
R8: 10K; R_0805_2012Metric; JLC C17414
R9: 150Ω; R_0603_1608Metric; JLC C114608
R10, R12: 2KΩ; R_0603_1608Metric; JLC C22975
S1: TL1105DF160Q; SW_TL1105DF160Q; PARTREV A; JLC C273469
TP6: GRAPHIC; DUCKY_ICON
U1: MCP73831T-2ACI/OT; BATT_Charger_SOT-23-5_Min_Silk; JLC C424093

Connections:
5V5: C2.1, C3.1, D4.1 (K), D7.2 (A), IC1.6 (VOUT), JP5V5.1 (A), R2.1, R5.1
5V5_MIST: C5.1, C6.1, D7.1 (K), L2.1
AO3400_DRIAN: J4.2, L2.2, Q2.3 (D)
BATT+: C8.1, D2.2 (A), J6.1, U1.3 (VBAT)
BATT-: C1.2, C2.2, C3.2, C5.2, C6.2, C7.2, C8.2, D3.2 (A), D4.2 (A), D6.2 (A), H1.1, H2.1, H3.1, IC1.4 (GND), J1.13 (GND), J3.6, J4.MP1, J4.MP2, J6.2, J6.MP1, J6.MP2, Q2.2 (S), R1.2, R3.2, R6.2, R7.2, R8.2, R9.2, R10.2, R11.2, U1.2 (VSS)
D0_MIST_PWM_3V3: J1.1 (D0), J2.1, JPD2.1 (A)
D1_MIST_PWM_3V3: J1.2 (D1), J2.2, JPD1.1 (A)
D2_CS: J1.3 (D2), J2.3, JPD3.1 (A)
D3_TPS_EN: J1.4 (D3), J2.4, JP1.1 (A)
D4: J1.5 (D4), J2.5
D5: J1.6 (D5), J2.6
D6_BUTTON: J1.7 (D6), J2.7, JPD6.1 (A)
D7_LED: J1.8 (D7), J3.1, JPD7.1 (A)
D8: J1.9 (D8), J3.2
D9: J1.10 (D9), J3.3
D10: J1.11 (D10), J3.4
FB: IC1.1 (FB), R2.2, R3.1
L_LEG3: J4.1, L2.3
MIST_PWM_3V3: D6.1 (K), JPD1.2 (B), JPD2.2 (B), Q1.2 (S), R4.2
MIST_PWM_5V5: C4.2, Q1.3 (D), R5.2
unnamed: C4.1, D3.1 (K), Q2.1 (G), R6.1
unnamed: IC1.2 (EN), JP1.2 (B), R1.1
unnamed: J5.1, JPD7.2 (B), LED2.2 (A)
unnamed: J5.2, LED2.1 (K), R9.1
unnamed: JP5V5.2 (B), LED1.2 (A)
unnamed: JPD3.2 (B), R11.1, R13.2
unnamed: JPD6.2 (B), R8.1, S1.1, S1.2
unnamed: LED1.1 (K), R7.1
unnamed: LED3.1 (K), R12.1
unnamed: R10.1, U1.5 (PROG)
unnamed: R12.2, U1.1 (STAT)
SW: IC1.5 (SW), L1.2
XIAO3V3: J1.12 (3V3), J3.5, Q1.1 (G), R4.1, S1.3, S1.4
XIAO5V: C7.1, D2.1 (K), D5.2 (A), J1.14 (5V), J3.7, LED3.2 (A), R13.1, U1.4 (VDD)
XIAO5V_DIO: C1.1, D5.1 (K), IC1.3 (VIN), L1.1

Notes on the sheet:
GRAPHICS & MOUNTING HOLES
CONNECTORS & JUMPERS
BATTERY IC
XIAO ESP32-C6 SOCKET
LED & SWITCH
10K = 100mA 5.0K = 200mA 2.0K = 500mA 1.0K = 1000mA
LOGIC VOLTAGE LEVEL SHIFTER
3V3 TO 5V5 BOOSTER
MIST COMPONENTS
Autotranformer
5V5 Noise Filter
CURRENT SENSE

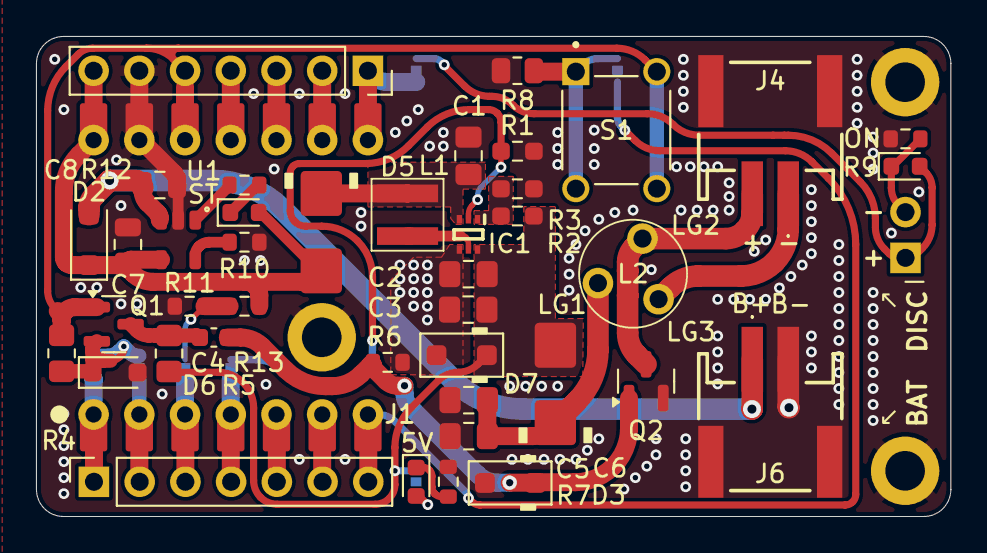
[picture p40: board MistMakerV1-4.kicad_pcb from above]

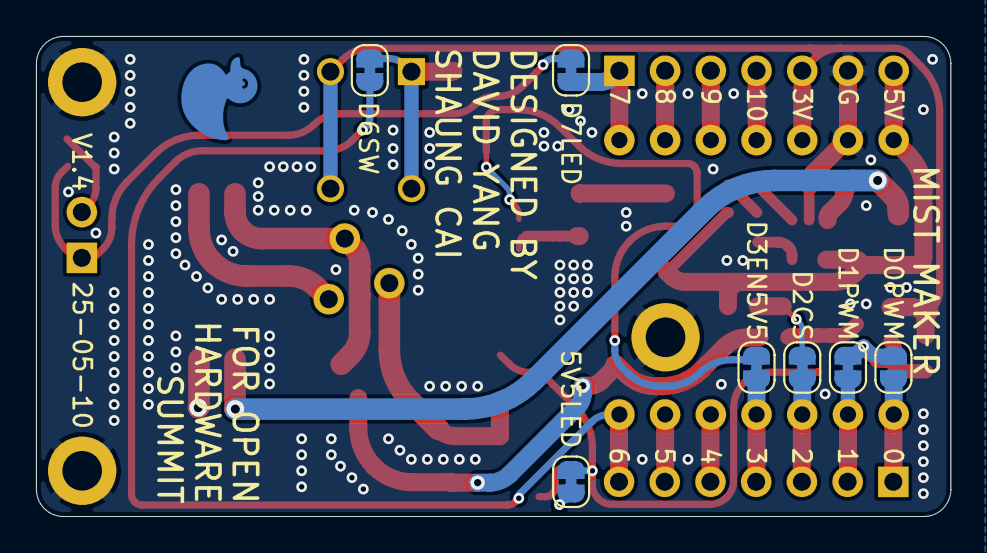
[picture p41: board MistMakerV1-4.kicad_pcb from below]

Board: 2 copper layers, 50.8 x 26.7 mm, 54 parts (8 on the bottom side), 35 nets.

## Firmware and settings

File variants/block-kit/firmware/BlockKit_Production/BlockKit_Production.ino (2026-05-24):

// Block Kit V0.1 — production firmware (Phase A).
//
// Top-level state machine + main loop. Three container-driven states drive
// the mist and LED ring; an orthogonal g_ledsHidden flag (short-press toggle)
// fades the LED strip without touching mist.
//
//   IDLE                    — undocked: soft exp(sin) breath on all 14 LEDs.
//   RUNNING                 — docked: gaussian swell wave + wave-modulated mist.
//   TRANSITION_FROM_RUNNING — just lifted: mist hard-stops, wave dims to 0.
//
// Wave-mist sync: while RUNNING, mist drive is gated by the wave's gaussian
// sampled 1 LED above the strip (the piezo's physical position). See
// mistOutLevel() here + waveIntensityAtPiezo() in led_driver.ino.
//
// SAFETY: container lift hard-stops mist (mistEnable(false)); OTA upload
// hard-stops mist (see ota.ino); boost rail is forced LOW first in setup().

#include <Wire.h>
#include <Preferences.h>
#include <nvs_flash.h>
#include "pins.h"
#include "config.h"

// ---- Forward declarations of helpers defined in sibling .ino files ----
void mistInit(); bool mistIsRunning(); bool mistIsInhibited();
void mistApply(uint8_t); void mistHardStop(); void mistEnable(bool);
void containerInit(); bool containerIsPresent(); bool containerRawPresent();
ContainerEvent containerPoll();
void buttonInit();    ButtonEvent buttonPoll();
void ledInit(); void ledRender(uint8_t); void ledAllOff(); void ledWalk();
void ledSetMode(LedMode);
uint8_t waveIntensityAtPiezo(uint32_t now);
void statusLedInit(); void statusLedSet(bool); void statusLedFlash(bool enteringDemo);
void currentSenseInit(); void currentSenseTick();
void currentSenseLogPlot(uint8_t); void currentSenseToggleScope();
void currentSenseTogglePlotMute();
float currentMeanMa(); float currentVarMa2();
// Piezo-sense classifier (see piezo_sense.ino):
PiezoState piezoState();
float      piezoLastProbeMa();
uint32_t   piezoWaterCountdownS();
void       piezoResetForNewDock();
void       piezoSensePeriodicWaterCheck();
void       piezoSensePeriodicDiscCheck();
bool       piezoAutoProbeForDisc();
float      piezoCalibrateWaterBaseline();
// New in production firmware:
void logInit();
size_t logSnapshot(char*, size_t);
void logPrintln(const char* s);
void logPrintf(const char* fmt, ...);
void wifiInit(); void wifiTick(); bool wifiIsSetupMode();
void wifiForgetAndReboot();
const char* wifiHostname();
void otaInit(); void otaHandle();
void webInit(); void webHandle();
// State accessors used by the web server module:
AppState  appCurrentState();
uint8_t   appUserLevel();
uint8_t   appUserLedLevel();
uint8_t   appCurrentLevel();
bool      appLedsHidden();
void      appToggleLedsHidden();
void      appKickLedWalk();
void      appSetLedLevel(uint8_t level);
void      appSetMistLedLinked(bool linked);

// ---- App-level state ----
static AppState g_state             = AppState::IDLE;  // boot default = soft breath
static uint8_t  g_userLevel         = CFG_DEFAULT_LEVEL_DEFAULT;  // overwritten from cfg in setup()
static uint8_t  g_targetLevel       = 0;    // state-driven target for the mist smoother
static uint8_t  g_currentLevel      = 0;    // smoothed mist drive level
// Parallel pair for the LED strip: when cfg.mistLedLinked the user-level
// setter mirrors mist→LED automatically, so legacy single-knob behaviour is
// preserved. When unlinked, the wave-slider on the web UI drives userLedLevel
// independently and the LED brightness rides its own smoother.
static uint8_t  g_userLedLevel      = CFG_DEFAULT_LEVEL_DEFAULT;
static uint8_t  g_targetLedLevel    = 0;
static uint8_t  g_currentLedLevel   = 0;
static int8_t   g_levelAdjustDir    = -1;   // -1 = next long-press dims, +1 = brightens
static uint32_t g_lastSmoothMs      = 0;
static uint32_t g_lastRampMs        = 0;
static uint32_t g_lastStatPrintMs   = 0;
// One-shot: pick the fast step for the next upward ramp (post-lift restore).
// Cleared once the smoother reaches target.
static bool     g_fastLevelUp       = false;

// LED visibility — orthogonal to AppState. Short-press toggles g_ledsHidden;
// a separate smoother fades g_ledScale 0↔255 over ~640 ms, multiplying the
// baseLevel handed to ledRender() so the strip fades cleanly instead of
// snapping. Mist is NOT affected by this flag — it follows g_currentLevel
// (wave-modulated in RUNNING) so the diffuser keeps running at the user-set
// level even while the visuals are blanked.
static bool     g_ledsHidden       = false;
static uint8_t  g_ledScale         = 255;   // smoothed: 0 (hidden) … 255 (visible)
static uint8_t  g_ledScaleTarget   = 255;   // 0 or 255, set by short-press
static uint32_t g_lastLedScaleMs   = 0;

// Demo mode — orthogonal to AppState. True = WiFi/OTA/web were skipped at
// boot and current sense is forced as the dock trigger; the device runs
// fully offline. Mirrors configIsDemoMode() at boot; the only thing that
// can flip it at runtime is the 5-tap toggle, which writes NVS and reboots,
// so this variable is read-only after setup() returns.
static bool     g_demoMode         = false;

// 5-tap toggle gesture (shared by the boot-time window AND the runtime
// onButtonEvent handler). Lives at the top of the file so both call sites
// see the same constants without a forward-declaration dance.
static constexpr uint8_t  DEMO_TOGGLE_TAPS    = 5;
static constexpr uint32_t DEMO_TOGGLE_GAP_MS  = 400;

static void enterIdle();
static void enterRunning();
static void enterTransitionFromRunning();

// ----------------------------------------------------------------------
// Factory reset via triple-tap of the physical reset button.
//
// On every boot we increment a counter in a dedicated NVS namespace. After
// the device runs cleanly for TAP_CLEAR_MS we wipe the counter. If the
// user resets TAP_THRESHOLD times in a row (each boot reaching less than
// TAP_CLEAR_MS), nvs_flash_erase() wipes the entire NVS partition —
// blockkit config blob, admin/OTA passwords, WiFi credentials, RF cal —
// and the device reboots into the captive portal as if it were factory new.
// ----------------------------------------------------------------------
static constexpr const char* TAP_NS         = "factory";
static constexpr const char* TAP_KEY        = "rc";
static constexpr uint8_t     TAP_THRESHOLD  = 3;
static constexpr uint32_t    TAP_CLEAR_MS   = 5000;
static uint32_t g_tapClearAtMs = 0;

static void appNvsWipeAndReboot() {
  Serial.println("[FACTORY] wiping NVS partition + rebooting");
  Serial.flush();
  // Safety: cut the boost rail before the (blocking) NVS erase.
  pinMode(PIN_BOOST_EN, OUTPUT);
  digitalWrite(PIN_BOOST_EN, LOW);
  nvs_flash_erase();   // wipes blockkit cfg, WiFi creds, WiFiManager state, RF cal
  nvs_flash_init();    // re-init the empty partition so next boot is clean
  delay(100);
  ESP.restart();
}

static void checkAndArmTapCounter() {
  Preferences p;
  if (!p.begin(TAP_NS, /*readOnly=*/false)) return;
  const uint8_t count = uint8_t(p.getUChar(TAP_KEY, 0) + 1);
  p.putUChar(TAP_KEY, count);
  p.end();
  Serial.printf("[FACTORY] reset-tap counter: %u/%u\n", count, TAP_THRESHOLD);
  if (count >= TAP_THRESHOLD) appNvsWipeAndReboot();  // never returns
  g_tapClearAtMs = millis() + TAP_CLEAR_MS;
}

// Unconditionally clear the factory-reset tap counter. Used both by the
// runtime "5 seconds of stable operation" path AND by any setup()-time
// reboot path (boot-tap demo toggle) that needs to make sure its own
// reboot is not counted as a partial boot toward the 3-tap factory wipe.
static void clearFactoryTapCounter() {
  Preferences p;
  if (p.begin(TAP_NS, /*readOnly=*/false)) {
    p.putUChar(TAP_KEY, 0);
    p.end();
  }
  g_tapClearAtMs = 0;
}

static void clearTapCounterIfStable() {
  if (g_tapClearAtMs == 0) return;
  if (millis() < g_tapClearAtMs) return;
  clearFactoryTapCounter();
}

// Public entry — called by /api/cmd/factory-reset.
void appFactoryReset() { appNvsWipeAndReboot(); }

// ----------------------------------------------------------------------
// Demo-mode toggle — invoked by the 5-tap gesture in onButtonEvent().
//
// Flips the persisted demo flag, flashes the status LED for visual
// confirmation, and reboots so setup() re-runs the WiFi/web init from a
// clean slate. Going via reboot (rather than live tear-down) avoids having
// to teach wifiInit()/webInit() how to undo themselves and re-running
// WiFiManager's 3-minute portal block on the way back to config mode.
// Mist + boost rail are cut first so the reboot can't leave the piezo
// driving — same safety pattern as appNvsWipeAndReboot().
// ----------------------------------------------------------------------
static void toggleDemoMode() {
  const bool enteringDemo = !g_demoMode;
  Serial.printf("[DEMO] %s mode — rebooting\n", enteringDemo ? "entering DEMO" : "returning to CONFIG");
  Serial.flush();
  mistHardStop();
  digitalWrite(PIN_BOOST_EN, LOW);
  configSetDemoMode(enteringDemo);
  clearFactoryTapCounter();        // demo toggle is a deliberate reboot, not a "failed boot"
  statusLedFlash(enteringDemo);    // blocking ~600 ms (enter) or ~1000 ms (exit)
  ESP.restart();                   // never returns
}

// ----------------------------------------------------------------------
// Boot-time demo-mode entry — the escape hatch that makes the device usable
// offline on a fresh unit (or in a venue with no reachable WiFi). Without
// this window, wifiInit() blocks in WiFiManager's captive portal for 3
// minutes and then reboots, so the runtime 5-tap handler in onButtonEvent()
// could never fire on a no-WiFi unit.
//
// Same gesture as runtime (5 short presses with <DEMO_TOGGLE_GAP_MS between
// each) so users only need to remember one thing. Status LED is held at the
// dim "waiting" level so the user has a visible cue that the window is open;
// it goes dark when the window expires and CONFIG-mode boot continues.
// ----------------------------------------------------------------------
static constexpr uint32_t DEMO_BOOT_WINDOW_MS = 3000;

static void awaitDemoTapAtBoot() {
  Serial.printf("[APP] tap user button 5× within %us to enter demo mode\n",
                (unsigned)(DEMO_BOOT_WINDOW_MS / 1000));
  statusLedSet(true);
  const uint32_t windowEnd = millis() + DEMO_BOOT_WINDOW_MS;
  uint8_t  taps    = 0;
  uint32_t lastTap = 0;
  while (millis() < windowEnd) {
    if (buttonPoll() == ButtonEvent::ShortPress) {
      const uint32_t now = millis();
      if (now - lastTap > DEMO_TOGGLE_GAP_MS) taps = 0;
      lastTap = now;
      if (++taps >= DEMO_TOGGLE_TAPS) {
        Serial.println("[APP] boot-tap detected — entering demo mode, rebooting");
        Serial.flush();
        // Mirror the safety pattern from toggleDemoMode(): cut mist + boost
        // rail before restart so a future change in setup() init order can
        // never leave the piezo driving across the reboot. Today mistInit()
        // has already run and the rail is LOW; these calls are belt-and-
        // braces for whoever rearranges setup() next.
        mistHardStop();
        digitalWrite(PIN_BOOST_EN, LOW);
        configSetDemoMode(true);
        clearFactoryTapCounter();
        statusLedFlash(/*enteringDemo=*/true);
        ESP.restart();            // never returns
      }
    }
    delay(2);                     // crude pacing — buttonPoll's debounce does the real work
  }
  statusLedSet(false);
  // Drain any in-flight button activity from the window so the first runtime
  // onButtonEvent() doesn't see a stale release as ShortPress #1 (a press
  // started during the last ~debounce ms of the window would otherwise leak
  // into the runtime 5-tap counter AND toggle the LED visibility once for
  // free). Bounded wait so a user holding the button forever doesn't stall.
  const uint32_t releaseDeadline = millis() + 500;
  while (digitalRead(PIN_BUTTON) == HIGH && millis() < releaseDeadline) delay(2);
  const uint32_t drainEnd = millis() + 60;     // > cfg.buttonDebounceMs default of 50
  while (millis() < drainEnd) { buttonPoll(); delay(2); }
}

// ----------------------------------------------------------------------
// State transitions
// Idempotent — calling enterX() when already in state X is a no-op so spam
// from serial commands or repeated reed edges doesn't churn log lines.
// Leaving any state where mist may be active (RUNNING / TRANSITION_FROM_
// RUNNING) locks the mist (mistEnable(false)) so the LED smoother's non-
// zero level can't sneak the boost rail back on; entering RUNNING unlocks
// it. D7 is driven by the main loop from containerIsPresent(), NOT from
// state, so the indicator follows the magnet not the mist.
// ----------------------------------------------------------------------
static bool mistMayBeActive(AppState s) {
  return s == AppState::RUNNING || s == AppState::TRANSITION_FROM_RUNNING;
}

static void enterIdle() {
  // Post-transition (container just lifted) — use the SLOW smoother step
  // instead of the fast restore. The previous "brisk restore" (~640 ms)
  // produced a visible brightness flash when the breath's exp(sin) phase
  // happened to be near its inhale peak at the moment baseLevel ramped up.
  // With the slow step (~1.3 s 0→255), the breath emerges gently and the
  // 1.1 s WAVE→BREATH crossfade has time to dissolve naturally. Net
  // experience: dim down to dark, then a soft breath swells in instead
  // of snapping on. (The g_fastLevelUp lane is still used by other code
  // paths if anything else needs it.)
  if (g_state == AppState::IDLE) return;
  const bool leavingMist = mistMayBeActive(g_state);
  g_state = AppState::IDLE;
  g_targetLevel    = g_userLevel;
  g_targetLedLevel = g_userLedLevel;
  g_fastLevelUp = false;            // slow restore — see comment at top of enterIdle()
  // BREATH triggers the WAVE→BREATH crossfade in led_driver when coming
  // from RUNNING / TRANSITION. led_driver collapses no-op mode changes
  // for us if we were already BREATH (e.g. boot).
  ledSetMode(LedMode::BREATH);
  if (leavingMist) mistEnable(false);
  logPrintln("[APP] -> IDLE");
}

static void enterRunning() {
  if (g_state == AppState::RUNNING) return;
  g_state = AppState::RUNNING;
  g_targetLevel    = g_userLevel;
  g_targetLedLevel = g_userLedLevel;
  // Mode flip directly to WAVE — led_driver runs an automatic 1.1 s
  // crossfade from whatever the previous mode was (BREATH in idle, or
  // WAVE-still-fading if we re-dock mid-transition). The old design used a
  // `g_pendingSwirl` flag to delay the mode flip until after the smoother
  // landed at target; that produced a visible "fade up then snap to chase"
  // moment — the specific complaint we're fixing here.
  ledSetMode(LedMode::WAVE);
  g_fastLevelUp = false;
  mistEnable(true);                        // re-arm the mist path
  logPrintln("[APP] -> RUNNING");
}

static void enterTransitionFromRunning() {
  if (g_state == AppState::TRANSITION_FROM_RUNNING) return;
  g_state = AppState::TRANSITION_FROM_RUNNING;
  g_targetLevel    = 0;
  g_targetLedLevel = 0;
  // Mode STAYS as WAVE — the wave naturally dims to black as baseLevel
  // ramps 255→0 (it scales the whole render uniformly). When the smoother
  // lands at 0 it auto-enters IDLE which kicks off the WAVE→BREATH
  // crossfade for the restore.
  g_fastLevelUp = false;
  mistEnable(false);                       // hard-stop + inhibit
  logPrintln("[APP] -> TRANSITION_FROM_RUNNING");
}

// ----------------------------------------------------------------------
// Wave-modulated mist level — only meaningful in RUNNING (mist is inhibited
// in every other state, so the value is don't-care there).
//
// factor (Q8) = cfg.mistWaveTroughQ8 + ((256 - trough) * gauss) >> 8
// mist_level  = (g_currentLevel * factor) >> 8
//
// gauss = waveIntensityAtPiezo(now) — the wave's gaussian sampled at the
// piezo position (1 LED above the top), so the mist crest follows the
// wave crest *across the top of the strip*, not at any visible LED.
// ----------------------------------------------------------------------
static uint8_t mistOutLevel(uint32_t now) {
  if (g_currentLevel == 0) return 0;
  const uint16_t trough = cfg.mistWaveTroughQ8;
  const uint16_t gauss  = uint16_t(waveIntensityAtPiezo(now));
  const uint16_t span   = (trough > 256u) ? 0u : uint16_t(256u - trough);
  const uint16_t factor = trough + ((span * gauss) >> 8);
  return uint8_t((uint16_t(g_currentLevel) * factor) >> 8);
}

// ----------------------------------------------------------------------
// LED visibility helpers — short-press flips g_ledsHidden and retargets the
// scaler. Long-press / state changes never touch this; it's strictly user-
// driven via the button.
// ----------------------------------------------------------------------
static void setLedsHidden(bool hidden) {
  if (g_ledsHidden == hidden) return;
  g_ledsHidden = hidden;
  g_ledScaleTarget = hidden ? 0 : 255;
  Serial.print("[APP] LEDs ");
  Serial.println(hidden ? "hidden (mist continues at set level)" : "visible");
}

// External hook for the web UI's hide/show toggle.
void appToggleLedsHidden() { setLedsHidden(!g_ledsHidden); }

// ----------------------------------------------------------------------
// Generic asymmetric ramp — pure, no globals. One step up, a different step
// down (use the same value for symmetric easing). Clamps at target so we
// never overshoot.
// ----------------------------------------------------------------------
static uint8_t rampToward(uint8_t current, uint8_t target, uint8_t stepUp, uint8_t stepDown) {
  if (current < target) {
    const uint8_t room = target - current;
    return current + ((room < stepUp) ? room : stepUp);
  }
  if (current > target) {
    const uint8_t room = current - target;
    return current - ((room < stepDown) ? room : stepDown);
  }
  return current;
}

// Level smoother — runs every cfg.levelSmoothTickMs. Asymmetric: a one-shot
// fast lane (g_fastLevelUp) lets the post-lift breath restore feel brisk.
// State-machine side effect: when the smoother lands on 0 in
// TRANSITION_FROM_RUNNING, auto-enter IDLE to start the WAVE→BREATH crossfade.
static void smoothLevel() {
  const uint32_t now = millis();
  if (now - g_lastSmoothMs < cfg.levelSmoothTickMs) return;
  g_lastSmoothMs = now;

  const uint8_t stepUp = g_fastLevelUp ? cfg.levelSmoothStepUpFast : cfg.levelSmoothStepUp;
  g_currentLevel    = rampToward(g_currentLevel,    g_targetLevel,    stepUp, cfg.levelSmoothStepDn);
  g_currentLedLevel = rampToward(g_currentLedLevel, g_targetLedLevel, stepUp, cfg.levelSmoothStepDn);

  if (g_currentLevel != g_targetLevel) return;
  // In unlinked mode the LED may still be ramping when the mist hits 0
  // (mist target is lower than LED target during normal use, but on lift
  // both targets go to 0 — and if LED was higher it has further to fall).
  // Wait for BOTH smoothers before declaring the transition complete so
  // the wave fully fades to black before BREATH crossfade kicks in.
  if (g_currentLedLevel != g_targetLedLevel) return;
  g_fastLevelUp = false;
  if (g_state == AppState::TRANSITION_FROM_RUNNING && g_targetLevel == 0) {
    enterIdle();
  }
}
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
void loop() {
  // Networking handled FIRST every loop so an OTA recovery push can still
  // land even if a downstream subsystem (LED driver, smoother) misbehaves.
  // Skipped entirely in demo mode — the radio was never started, the web
  // server was never bound, so calling these would be a no-op but we save
  // the cycles and keep the loop's intent obvious.
  if (!g_demoMode) {
    otaHandle();
    webHandle();
    wifiTick();
  }

  const uint32_t now = millis();
  pollSerial();

  // Subsystem ticks
  currentSenseTick();
  smoothLevel();
  smoothLedScale();
  clearTapCounterIfStable();   // 5 s after boot, reset the triple-tap counter

  // Apply smoothed level to outputs.
  //
  // Mist: wave-modulated at the piezo position (only meaningful in RUNNING;
  // mist is inhibited everywhere else, so mistApply is a no-op there).
  // LEDs: scaled by g_ledScale (the short-press hide/show fade) so the
  // strip can be blanked without touching mist.
  mistApply(mistOutLevel(now));
  // LEDs ride their own smoothed level (g_currentLedLevel) so the wave
  // slider in unlinked mode can dim the visuals without touching the mist.
  // In linked mode appSetLevel() keeps userLedLevel in lockstep with
  // userLevel, so behaviour is identical to the pre-link era.
  const uint8_t ledBase =
      uint8_t((uint16_t(g_currentLedLevel) * uint16_t(g_ledScale)) >> 8);
  ledRender(ledBase);

  // Input edges + diagnostics
  onContainerEvent(containerPoll());
  onButtonEvent(buttonPoll());

  // Piezo classifier dispatch — RUNNING runs the water probe + fault check;
  // IDLE+useAsReed runs the auto-probe for dock detection. Mutually exclusive.
  if (g_state == AppState::RUNNING) {
    piezoSensePeriodicWaterCheck();
    if (cfg.senseUseAsReed) piezoSensePeriodicDiscCheck();   // reed events are ignored — need fast removal signal
    const PiezoState ps = piezoState();
    if (ps == PiezoState::WATER_DEPLETED || ps == PiezoState::DISC_DISCONNECTED) {
      logPrintln(ps == PiezoState::WATER_DEPLETED
                       ? "[APP] water depleted — fading out"
                       : "[APP] disc disconnected — fading out");
      enterTransitionFromRunning();
    }
  } else if (g_state == AppState::IDLE && cfg.senseUseAsReed) {
    if (piezoAutoProbeForDisc()) enterRunning();
  }

  // D7 reflects container presence directly (dim when waiting for a dock,
  // off when docked) unless a web-UI override forces a specific state.
  if (g_statusLedOverride == 0)      statusLedSet(false);
  else if (g_statusLedOverride == 1) statusLedSet(true);
  else                               statusLedSet(!containerIsPresent());

  currentSenseLogPlot(uint8_t(g_state));
  statusTick();

  // Web UI may request a one-shot LED chase via /api/cmd/walk.
  if (g_kickLedWalk) {
    g_kickLedWalk = false;
    ledWalk();
  }
}

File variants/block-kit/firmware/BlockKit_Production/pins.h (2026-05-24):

// Block Kit V0.1 — single source of truth for pins, hardware constants, and
// the *defaults* for every runtime-tunable.
//
// Anything a user might reasonably want to tweak from the web UI lives here
// as a CFG_DEFAULT_* constexpr. config.ino loads those into a runtime
// `Config cfg{...}` struct (overlaying NVS-saved values if present), and
// every other .ino reads `cfg.foo` instead of the constant directly.
//
// Hardware properties (GPIOs, piezo resonance, INA180 gain, LUT-binding
// constants, the piezo's physical offset above the strip) stay as plain
// constexpr — those are facts about the board, not things to change at
// runtime.

#pragma once
#include <Arduino.h>

// ---------- GPIO assignments ----------
//
// The Block Kit V0.1 PCB physically only mates with a XIAO socket. The XIAO
// platform headers already expose D0..D10 as C++ constants that match the
// silkscreened pin labels, so on XIAO boards we just use those directly —
// no preprocessor remapping, nothing for the C preprocessor to get wrong.
//
// For non-XIAO ESP32 dev boards (Adafruit QT Py family) we keep the sketch
// buildable as a porting / "does it compile" target, by picking GPIOs from
// labels (A0..A3, TX, RX) that those board variants do expose. The Block
// Kit PCB itself does not mate with these boards — the firmware will run,
// but won't drive any real hardware.
//
// Any other board → #error so silent miswiring (the original V0.1 bug) is
// impossible.

#if defined(ARDUINO_XIAO_ESP32C6) || \
    defined(ARDUINO_XIAO_ESP32S3) || \
    defined(ARDUINO_XIAO_ESP32S3_PLUS)

  // ---- XIAO socket form factor — Block Kit V0.1 production target ----
  constexpr uint8_t PIN_MIST_PWM     = D0;   // 108.7 kHz PWM to MOSFET gate
  constexpr uint8_t PIN_REED         = D10;  // Reed switch (INPUT_PULLUP), LOW=docked
  constexpr uint8_t PIN_CURRENT_ADC  = D2;   // INA180A3 via 1k+1uF filter
  constexpr uint8_t PIN_BOOST_EN     = D3;   // TPS61023 EN (HIGH = 5V rail on)
  constexpr uint8_t PIN_BUTTON       = D6;   // Active-HIGH, PCB 10k pull-down
  constexpr uint8_t PIN_STATUS_LED   = D7;   // White LED, dim "waiting" indicator

#elif defined(ARDUINO_ADAFRUIT_QTPY_ESP32S3_NOPSRAM) || \
      defined(ARDUINO_ADAFRUIT_QTPY_ESP32S3_N4R2)    || \
      defined(ARDUINO_ADAFRUIT_QTPY_ESP32S2)         || \
      defined(ARDUINO_ADAFRUIT_QTPY_ESP32C3)         || \
      defined(ARDUINO_ADAFRUIT_QTPY_ESP32_PICO)

  // ---- Adafruit QT Py family — compile-only target ----
  constexpr uint8_t PIN_MIST_PWM     = TX;
  constexpr uint8_t PIN_REED         = RX;
  constexpr uint8_t PIN_CURRENT_ADC  = A0;
  constexpr uint8_t PIN_BOOST_EN     = A3;
  constexpr uint8_t PIN_BUTTON       = A2;
  constexpr uint8_t PIN_STATUS_LED   = A1;

#else
  #error "Block Kit V0.1 firmware: please select a supported board in Arduino IDE \
> Tools > Board. Supported: XIAO_ESP32C6 (production), XIAO_ESP32S3, \
XIAO_ESP32S3_PLUS, or any Adafruit QT Py ESP32 variant (compile-only)."
#endif

// ---------- Hardware constants (NOT runtime-tunable) ----------

// Mist PWM
constexpr uint32_t MIST_FREQ_HZ    = 108700;  // ceramic disc resonance
constexpr uint8_t  MIST_PWM_RES    = 8;       // 8-bit -> 0..255 duty

// Wave ↔ mist sync — the piezo physically sits 1 LED *above* the top of the
// strip (index 0). Used by waveIntensityAtPiezo() in led_driver.ino to sample
// the gaussian at that offset so the mist crest follows the wave crest as
// it passes the top of the strip. Physical placement, not a tunable.
constexpr uint16_t MIST_PIEZO_OFFSET_LEDS_Q8 = 256;  // Q8: 256 = 1 LED

// Status LED PWM
constexpr uint32_t STATUS_LED_FREQ_HZ = 5000;
constexpr uint8_t  STATUS_LED_RES     = 8;

// INA180 current sense
constexpr float    CURRENT_SENSE_FACTOR = 3.0f;     // V per A (gain×R_shunt)
constexpr uint16_t CURRENT_SAMPLE_HZ    = 1000;     // ADC sample rate target
constexpr uint16_t CURRENT_WINDOW_N     = 256;      // sliding window length
constexpr uint32_t SCOPE_PRINT_HZ       = 100;      // scope-mode print rate

// IS31FL3731 LED strip topology
constexpr uint8_t  LED_COUNT             = 14;
constexpr uint8_t  LED_IS31_ADDR         = 0x74;
constexpr uint8_t  LED_IS31_FRAME        = 0;
constexpr uint16_t LED_TICK_MS           = 20;      // 50 fps render

// Gauss LUT step in led_driver.ino is hard-coded to σ=4 LEDs (Q8 = 1024).
// Changing this requires retuning the LUT, so it's not user-tunable.
constexpr uint16_t WAVE_SIGMA_LEDS_Q8    = 4 * 256;
constexpr int16_t  WAVE_TRAVEL_PAD_Q8    = 3 * 4 * 256;  // 3σ pad each end

// 14 LED numbers on Matrix B, ordered top (index 0) to bottom (index 13).
constexpr uint8_t LED_MAP[LED_COUNT] = {
   8,  9, 10, 11, 12, 13, 14, 15,   // CB1 row: top, LEDs 1..8
  24, 25, 26, 27, 28, 29,           // CB2 row: LEDs 9..14 (bottom)
};

// Serial
constexpr uint32_t SERIAL_BAUD          = 115200;
constexpr uint32_t PLOT_PRINT_HZ        = 20;       // [PLOT] CSV rate when scope mode off
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

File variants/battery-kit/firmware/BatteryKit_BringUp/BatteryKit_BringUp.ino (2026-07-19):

// Mist Maker Battery Kit V0.4 / V0.4.1 — BringUp sketch.
// (Pins D0–D7 are identical on V0.3; the `u` USB/mux test needs V0.4+.
//  V0.4.1 — the July 2026 production spin — runs the same firmware; see
//  pins.h for what changed electrically and SELF-TEST below for the fast
//  automated checkout.)
//
// Bare-bones per-feature verification, no library required. Flash this on a
// freshly assembled board, then EITHER hold the button >= 1.5 s (or send `a`)
// for the AUTOMATED SELF-TEST — a ~10 s pass/fail checkout of everything
// measurable without hands — or walk the manual checklist:
//   1. "does the button work?"            -> press it: mist + LED toggle
//   2. "does the boost rail come up?"     -> `t`, scope the 5 V rail or watch mist
//   3. "is the INA180 reading anything?"  -> `c` prints one current reading
//   4. "is the mux ST sense alive?"       -> `u` reads USB present (D8 HIGH);
//                                            meter TP3 for the cell/LOW case
//   5. "does the battery divider read?"   -> `b` prints volts + validity
//   6. "dry vs wet separation?"           -> `s` streams CSV for the Plotter
//   7. "does dimming work?"               -> `0`..`9` sets duty
//   8. "does the mux hand over cleanly?"  -> cell in, mist on, unplug USB,
//      replug, press `u`: the flip counter shows the USB->BATT->USB handoff
//      happened, and a boot reason still reading "power-on" proves the
//      TPS2116's ~1.3 ms break-before-make gap didn't brown out the MCU.
//
// The TPS2116 power mux (V0.4) runs the board off USB whenever it's plugged
// in, so Vbatt reflects true state-of-charge only on the cell. D8 (mux ST)
// tells us which: HIGH = USB, LOW = battery. `b`/`[STAT]` always print the
// voltage + OK/LOW/CRITICAL tag and add "[USB - charging]" on USB (where the
// number tracks the charger, not SoC).
//
// NOTE: on this board USB is the only serial link, so over the console D8
// almost always reads HIGH (USB). To confirm the LOW/cell state, meter TP3
// (or D8) with the cell in and USB out — you can't watch it flip over serial.
//
// Expected (XIAO C6, INA180A3, 30 mOhm shunt, duty 64):
//   no disc ~0 mA · disc dry ~70-100 mA · disc in water ~130-200 mA
//   D8: on USB reads HIGH (~2.6 V), on battery reads LOW (~0 V)
// Battery: 4.2 V full · 3.7 V nominal · <3.45 V low · <3.20 V critical
//
// For real applications use the MistMaker library (>= 2.1.0) instead:
// https://github.com/owochel/MistMaker

#include "pins.h"
#include <esp_system.h>   // esp_reset_reason(): brownout vs power-on at boot

static const char FW_VERSION[] = "1.1.0";   // BringUp sketch, not the library

static bool     g_on        = false;
static uint8_t  g_duty      = MIST_DUTY_FULL;
static bool     g_scope     = false;
static bool     g_btnDeb    = false;
static bool     g_btnRaw    = false;
static uint32_t g_btnEdgeMs = 0;
static uint32_t g_btnPressMs  = 0;     // when the debounced press began
static bool     g_btnLongFired = false; // long-press consumed (skip the toggle)
static uint32_t g_lastStatMs  = 0;
static uint32_t g_lastScopeMs = 0;

// Power-source handoff bookkeeping (survives USB unplug, unlike serial output):
// the mux switches USB<->cell in ~1.3 ms with the serial link down, so we count
// flips here and let `u` report them after the fact.
static bool     g_lastUsb    = false;
static uint16_t g_usbFlips   = 0;
static uint32_t g_lastFlipMs = 0;

static const char* resetReasonStr() {
  switch (esp_reset_reason()) {
    case ESP_RST_POWERON:   return "power-on";
    case ESP_RST_BROWNOUT:  return "BROWNOUT";   // mux handoff gap too deep
    case ESP_RST_SW:        return "software";
    case ESP_RST_PANIC:     return "panic";
    case ESP_RST_DEEPSLEEP: return "deep-sleep wake";
    case ESP_RST_WDT: case ESP_RST_INT_WDT: case ESP_RST_TASK_WDT:
                            return "watchdog";
    default:                return "other";
  }
}

static inline float adcToMa(uint16_t raw) {
  const float volts = (float(raw) * 3.3f) / 4095.0f;
  return (volts * 1000.0f) / CURRENT_SENSE_FACTOR;
}

static float readMa(uint16_t sampleMs = 50) {
  uint32_t sum = 0, n = 0;
  const uint32_t start = millis();
  while (millis() - start < sampleMs) { sum += analogRead(PIN_CURRENT_ADC); n++; }
  return n ? adcToMa(uint16_t(sum / n)) : 0.0f;
}

static float readBatteryVolts() {
  // analogReadMilliVolts() applies the C6's factory eFuse calibration, so the
  // reading is linear millivolts (raw analogRead is nonlinear — #11324).
  uint32_t sum_mV = 0;
  for (uint8_t i = 0; i < 16; i++) sum_mV += analogReadMilliVolts(PIN_BATT_ADC);
  return (float(sum_mV) / 16.0f) / 1000.0f * BATT_DIVIDER_RATIO;
}

// Mux status on D8 (V0.4+): HIGH = load on USB (VIN1), LOW = load on the cell
// (VIN2). Vbatt is a trustworthy state-of-charge only when this is false.
static inline bool onUsbPower() {
  return digitalRead(PIN_USB_SENSE) == HIGH;
}
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

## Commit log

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2026-05-13 Fix three review findings on Phase A firmware
    - led_driver.ino: replace g_is31.clear() (not in stock Adafruit lib) with a
    manual zero loop over the 14 populated positions. Should compile against
    both stock and David's fork.
    - BlockKit_Test.ino: drop String from the serial command parser, switch to a
    fixed 32-char buffer + simple integer-tail parser. Matches the plan's
    no-dynamic-allocation / no-String rule.
    - container.ino: seed g_containerPresent = false at boot so a container that
    is already docked at power-on edge-triggers Inserted (after the 500 ms
    safety dwell), matching the comment in BlockKit_Test.ino setup().
    [BlockKit_Test.ino, container.ino, led_driver.ino]
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2026-05-13 Fix g_lastTickMs name collision across .ino files
    Arduino IDE concatenates every .ino in a sketch folder into a single
    translation unit before compiling. That means file-scope `static` doesn't
    actually limit visibility per-file -- three sibling files all declared
    `static uint32_t g_lastTickMs` and the compiler saw three redefinitions of
    the same name.
    Prefix each with its module: g_btnLastTickMs (button), g_ledLastTickMs
    (swirl), g_statusLastTickMs (D7 breathing). Behavior unchanged.
    [button.ino, led_driver.ino, status_led.ino]
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2026-05-13 Move reed switch from D1 to D10
    D1 was originally repurposed (via blue-wire rework) from its schematic role
    as the alt-PWM destination through JP02. Switching the reed to D10 -- which
    is unused on the Block Kit V0.1 schematic -- has three small advantages:
    - D1 stays in its documented schematic role; JP02 behavior is no longer
    entangled with the reed wiring.
    - D10 is physically opposite D0 (mist PWM) on the XIAO socket footprint,
    reducing any chance of PWM crosstalk into the reed line.
    - One less footnote in the bring-up checklist.
    The blue-wire rework on V0.1 boards is otherwise unchanged -- same effort,
    just a different destination pin. Verified compile on all three boards:
    XIAO_ES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
    [container.ino, pins.h]
2026-05-13 Fix LED driver: address Matrix B via setLEDPWM + LED_MAP
    The previous driver used drawPixel(x,y,…) from Adafruit_GFX, which writes
    the IS31FL3731's Matrix A. Block Kit V0.1 populates Matrix B only (CB1/CB2),
    so drawPixel calls "succeed" silently but never light a real LED. That was
    the cause of the dark column user reported during bring-up.
    Rewrite to David's working approach (his bench-validated test sketch):
    - Use setLEDPWM(lednum, pwm, 0) which writes the chip's PWM register space
    directly.
    - Replace LED_POSITIONS[14][2] (x,y) with LED_MAP[14] (lednums 8..15 for
    CB1 row, 24..29 for CB2 row) per IS31FL3731 datasheet Rev F Table 7.
    - Add a 2.2 gamma LUT so perceived brightn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
    [BlockKit_Test.ino, led_driver.ino, pins.h]
2026-05-13 Match working bench sketch on ADC + add `r` reed-state command
    David's bench-validated test sketch reads INA180 current correctly while my
    firmware was reporting 0 mA continuously. Diff against the working code
    turned up three differences in the mist/ADC path:
    1) ADC init. My code called analogReadResolution(12) and
    analogSetPinAttenuation(D2, ADC_11db) before the first read. The bench
    sketch does neither -- it just relies on arduino-esp32 v3.x defaults
    (12-bit, ~3.3 V full-scale) and calls pinMode(D2, INPUT). On ESP32-C6
    v3.3.8 the explicit attenuation call can leave the ADC returning 0; the
    defaults work. Switch to the bench-sketch recipe.
    2) mistOff didn't force D0 LOW af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
    [BlockKit_Test.ino, container.ino, current_sense.ino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]
2026-05-13 Harden input pins + add [STAT] live diagnostic
    David's bench tests reveal that in this firmware D10 reads LOW continuously
    (reed always "present") and D6 reads HIGH continuously (false long-press)
    even though his minimal test sketch reads D10 correctly with INPUT_PULLUP.
    That points at something in our richer setup() sequence disturbing the pin
    state after pinMode -- moving the input inits to the end and adding a
    defensive pull-down should clear both.
    Changes:
    - buttonInit(): pinMode INPUT -> INPUT_PULLDOWN. The PCB has an external
    10 k pull-down on D6, but if it has a cold joint or D6 floats during
    early boot the internal ~45 k pull-down keeps the input LOW. Button
    press still clean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
    [BlockKit_Test.ino, button.ino]
2026-05-13 Defensively re-apply pinMode in every reed and button poll
    David confirmed both D10 (reed) and D6 (button) read correctly in his
    minimal test sketches, but in this firmware D10 sits stuck LOW and D6 stuck
    HIGH. The pin numbers, wiring, and pinMode arguments are all correct. The
    only difference between his minimal sketch and this firmware is the rest of
    setup() -- Wire.begin, LEDC attaches, IS31FL3731 begin, ADC config, ledInit.
    Something in that chain on XIAO ESP32-C6 + arduino-esp32 v3.3.8 leaves the
    pin in a state where the internal pull-up/down isn't actually applied.
    Cheapest fix: re-apply pinMode at the top of every poll. ~1 us overhead per
    call (the poll runs every loop iteration anyw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
    [button.ino, container.ino]
2026-05-13 Fix pin-map bug: use ARDUINO_XXX guard for QT Py fallback, add `m` mute cmd
    Root cause of nearly every bring-up symptom this evening (D10 stuck LOW,
    D6 stuck HIGH, mean_mA=0, mist not running, current sense reading nothing):
    pins.h had a portability fallback guarded by `#if !defined(D0)`. The XIAO
    ESP32-C6 platform declares D0..D10 as C++ constants (`static const uint8_t
    D0 = 0;`), not as preprocessor macros. The C preprocessor cannot see C++
    constants, so `#if !defined(D0)` is ALWAYS true. The QT Py fallback was
    therefore firing on XIAO targets too -- substituting D0=5, D2=18, D3=8,
    D6=9, D7=17, D10=36 as preprocessor #defines that won the macro-expansion
    race against the C++ const declara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
    [BlockKit_Test.ino, button.ino, container.ino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]
2026-05-13 Rewrite pins.h with explicit per-board PIN_* blocks (drop Dx macro shim)
    The previous pins.h tried to make the sketch portable by #define-ing Dx
    macros for boards that don't expose XIAO-style pin labels. That approach
    backfired twice:
    1) David's question "shouldn't it be just D1, D2 etc?" is correct on
    XIAO boards. The XIAO platform header already exposes D0..D10 as
    C++ constants; remapping them via #define adds nothing.
    2) The C preprocessor can't see C++ constants, so the `#if !defined(D0)`
    guard was ALWAYS true and clobbered the XIAO map silently. That bug
    burned an entire bring-up session before [APP] PIN_*=(GPIO N) print
    made it obvious.
    Replace the shim w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
    [BlockKit_Test.ino, pins.h]
2026-05-13 Phase A UX overhaul: unified level + 3-state machine + luxurious ramps
    Major rework of the user experience based on bench testing feedback:
    UX changes
    ----------
    * One `g_userLevel` (0..255) drives BOTH mist PWM duty and LED ring
    brightness. Long-press the button to ramp it; LEDs and mist follow
    together. Mist duty = (level * 127) / 255 so level 255 = 50% PWM =
    full mist.
    * Three top-level states:
    - IDLE_LEDS_OFF — no container, ring dark, D7 dim
    - IDLE_LEDS_ON — no container, ring breathing, D7 dim (ambient mode)
    - RUNNING — container docked, mist active, ring breathing
    * Button short-press is now state-aware:
    - in IDLE_LEDS_OFF → IDLE_LEDS_ON (LEDs com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
    [BlockKit_Test.ino, led_driver.ino, mist.ino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]
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2026-05-13 Apply Phase A code review fixes (5 medium + 3 nit)
    Findings from a deep code review (Plan agent, opus) — applied the medium-
    severity bugs and the three NITs that earn their weight; skipped the
    verbose-style NITs (table-driven banner, clamp helper, etc.) since the
    inline versions read fine and the user picked "Medium" cleanup scope.
    MEDIUM:
    * led_driver.ino: phaseQ8 multiply overflowed uint32_t every ~262 s
    (now * 64 * 256 > 4.29G), producing a tiny breath glitch every ~4 min.
    Reduce `now` mod period BEFORE the multiply so the intermediate stays
    bounded.
    * BlockKit_Test.ino: enterIdleLedsOff() at end of setup() is idempotent
    and returns silently (state already matches static initi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
    [BlockKit_Test.ino, container.ino, led_driver.ino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]
2026-05-13 LED redesign: BREATH idle + SWIRL chase docked + cinematic removal
    User feedback: the ring is a 14-LED vertical strip (top=LED 1, bottom=
    LED 14), not a ring; the previous "always uniform breath" effect didn't
    match the intent. New behavior, agreed via question round before coding:
    * IDLE_LEDS_ON (boot default): all 14 LEDs do a soft uniform breath at
    the user level. Short-press still toggles to IDLE_LEDS_OFF (mute) and
    back. Boot now lands here instead of IDLE_LEDS_OFF.
    * RUNNING (container docked): mist on. LEDs first fade up in BREATH
    mode, AND THEN — once g_currentLevel lands on target — flip to SWIRL,
    a continuous rising chase. A bright head travels bottom (i=13) to top
    (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
    [BlockKit_Test.ino, led_driver.ino, pins.h]
2026-05-13 LED redesign: deep-dim exp(sin) BREATH + gaussian-swell WAVE + crossfade
    Reframes the LED experience around premium-ambient lighting cues. The prior
    design (subtle breath around baseLevel + rising vertical chase) read as
    "snappy" and "too bright in idle" — both fixed here.
    BREATH (idle, no container)
    - exp(sin) curve LUT (FastLED/ThingPulse-style) instead of plain sine. The
    curve is asymmetric: the exhale lingers at zero for several samples each
    cycle, giving the dramatic "dwell at black" the user asked for.
    - Output is capped to LED_BREATH_PEAK (38 ≈ 15% post-gamma) regardless of
    baseLevel, so idle stays *very dim* even at user_level=255 default. The
    old design's depth-around-b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
    [BlockKit_Test.ino, led_driver.ino, pins.h]
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2026-05-14 Sync mist drive to LED wave; short-press hides LEDs only
    While in RUNNING, mist drive is now modulated by the wave swell's
    gaussian intensity sampled at the piezo's position (1 LED above the top
    of the strip via MIST_PIEZO_OFFSET_LEDS_Q8). The mist rises with the
    visible swell, peaks once the wave has crossed the top (where the piezo
    physically sits), then dims down together with the top LED as the wave
    exits off-screen above. Trough is set to 92/256 ≈ 36% of full so the
    swing mirrors WAVE_BASE_LEVEL/255's own ratio — visible pulse, but
    proportional to the LED animation. waveCenterYQ8() is shared between
    the visible renderer and waveIntensityAtPiezo() so the two are
    guaranteed phase-lock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
    [BlockKit_Test.ino, led_driver.ino, pins.h]
2026-05-14 Add BlockKit_BringUp sketch for raw per-feature bench verification
    Minimal single-file Arduino sketch that exercises each Block Kit V0.1
    peripheral in isolation — no state machine, no animations, no smoother.
    Button press toggles boost rail + mist (50% PWM) + all 14 LEDs at a
    fixed brightness. Serial commands:
    t toggle (same as button)
    w LED chase, top-to-bottom, 1 s per LED
    c current-sense dump (mean / min / max mA over 100 reads)
    h help
    A periodic [STAT] line every 250 ms shows raw button, raw reed, mist
    state, and ADC mA so the Serial Monitor stays useful while idle. The
    slim pins.h carries only the GPIO map + frequencies + LED table —
    none of the production firmware's U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
    [BlockKit_BringUp.ino, pins.h]
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2026-05-14 Fix Block Kit Production firmware compile errors
    Five issues caught when the previous PR was compiled in Arduino IDE:
    1. CfgBlob struct moved from config.ino to config.h
    The Arduino IDE auto-generates forward declarations for .ino-file
    functions and inserts them at the TOP of the preprocessed file,
    BEFORE the file's own struct definitions. packBlob(CfgBlob&) and
    unpackBlob(const CfgBlob&) had their prototypes inserted before
    the struct existed -> "'CfgBlob' was not declared in this scope".
    Putting the struct in the header makes it visible to the
    auto-generated prototypes.
    2. Local "HEX" variable renamed to HEX_CHARS in configSha256Hex().
    Arduino's Print.h #defines H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
    [config.ino, web_server.ino]
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2026-05-14 Name LUT-indexing magic numbers as constexpr
    LUT_SIZE, LUT_MASK, GAUSS_LUT_SHIFT, GAUSS_FRAC_LSHIFT now self-document the
    breath/gauss math. Replace bare 64, 63 (0x3F), >>6, <<2 with named refs.
    Static_assert still guards the σ=4 LED invariant.
    [led_driver.ino]
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2026-05-14 Extract nvsPutString helper for config setters
    Replaces 3 repeated 4-line Preferences open/put/close blocks in
    configSetHostname, configSetAdminPassword, configSetOtaPassword.
    NVS keys and values unchanged — no risk to existing user configs.
    [config.ino]
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2026-05-14 Rename led_driver helpers and render locals for clarity
    breathQ to breathValue, gaussQ to gaussValue: Q is implementation detail
    that callers do not need to see.
    Render-function locals get descriptive names: y_q8 to waveCenterQ8,
    d_q8 to distQ8, g to gauss, led_q8 to ledPosQ8, piezo_q8 to piezoPosQ8,
    span_q8 to spanQ8. Q8 suffix kept on fixed-point values; vague single
    letters dropped.
    [led_driver.ino]
2026-05-14 Tidy alignment + tighten comment on app-state declarations
    Final review pass: realign columns after renames; shorten the
    g_fastLevelUp comment from 4 lines to 2.
    [BlockKit_Production.ino]
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2026-05-14 Redesign web UI: 2-tile quick controls + collapsed advanced + cleaner debug
    Status tab top: Mist tile (toggle + percent slider + flowing/ready sub) and
    LED Wave tile (toggle = hide/show LEDs, slider mirrors mist level). Below the
    tiles: reed pill with Force IDLE/RUNNING overrides, indicator-LED pill with
    Auto/On/Off override buttons. Below those: a friendly Mist Pulse Depth slider
    that translates 0-100% to/from the Q8 trough internally.
    Config tab: every existing fieldset is now inside a collapsed details panel
    labeled Advanced settings so the form is not the first thing you see.
    Debug tab: added Mute [PLOT] stream (m) button and a Serial-only commands
    cheat sheet (help, vN, r, k) so it is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
    [web_ui.h]
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2026-05-14 Address Codex review: fix slider race + confirm Force RUNNING
    1. Slider dragging flag now toggles on pointerdown/pointerup instead of
    input/change. Closes the race where a slow POST left dragging=null
    during the in-flight fetch, allowing SSE to snap the slider back.
    2. Force RUNNING button now shows a confirm dialog. Forcing RUNNING
    re-arms mist regardless of reed state — a stray tap could engage
    the piezo on an empty bottle. The override is still available for
    testing without a magnet, just with an explicit gate.
    [web_ui.h]
2026-05-14 Cap mistDutyMax and mistDutyMin at 200 (hardware-safe limit)
    Setting values above ~200 (78% duty) drives the piezo past the TPS61023
    boost converter's 2A current limit. The boost hiccups, battery rail
    develops large ripple, WiFi browns out, and the device becomes
    unreachable on the LAN. Bench-validated: 200 holds stable, 220+ does not.
    Range now enforced by configSetField() so the web UI cannot accidentally
    brick the device. Existing saved values >200 in NVS are not auto-clamped
    (use factory reset for those).
    [config.ino]
2026-05-14 Boot-safe: inhibit mist until enterRunning() unlocks
    g_mistInhibited now defaults to true so the boost rail cannot engage
    during the level smoother's boot-time 0->cfg.levelDefault ramp. The
    state machine starts in IDLE; enterRunning() unlocks via mistEnable(true)
    only after the reed debounce confirms a docked container.
    Symptom this fixes: device occasionally produced a brief puff of mist
    during the first ~1.3s after power-on, before the container check
    completed.
    [mist.ino]
2026-05-14 Add triple-tap-reset and /api/cmd/factory-reset endpoint
    Press the physical reset button 3 times within ~5 seconds of each boot and
    the firmware will wipe the entire NVS partition: config blob, admin/OTA
    passwords, WiFi credentials, and RF calibration cache. Device reboots into
    the captive portal as if it were factory-new.
    How it works: a tap counter in a dedicated 'factory' NVS namespace ticks
    up on every boot. After the device runs cleanly for 5 s the counter is
    cleared. Three boots in a row that never reach the clear point trigger
    nvs_flash_erase() + ESP.restart().
    The same wipe is exposed at POST /api/cmd/factory-reset (admin-auth
    gated) for web UI recovery. Both paths converge on the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
    [BlockKit_Production.ino, web_server.ino]
2026-05-14 Wire web UI Reset-to-defaults button to factory-reset endpoint
    Replaces the placeholder alert with a real call to /api/cmd/factory-reset.
    The confirm dialog is now honest: factory reset wipes config, WiFi creds,
    AND admin password (you have to redo captive portal).
    Also adds a Recovery section to the About tab documenting the triple-tap
    reset path so users have a written escape hatch if the web UI is unreachable.
    [web_ui.h]
2026-05-14 Address Codex review: gate factory-reset endpoint behind admin password
    The existing requireAuth() helper grants open access when no admin password
    is set yet (first-boot grace period). That is intentional for reversible
    writes but a real DoS hole on the destructive /api/cmd/factory-reset
    endpoint: a LAN attacker could wipe a freshly-provisioned device before
    the user finishes setting an admin password.
    Special-case the factory-reset handler to ALWAYS require an admin password,
    even during the grace period. Users who skip the password during captive
    portal still have a recovery path: the physical triple-tap reset button.
    That requires physical access, which is the natural authentication for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
    [web_server.ino]
2026-05-14 Tighten duty cap from 200 to 170 for safety headroom
    200 was the empirical edge where TPS61023 boost OCP starts to trigger.
    Capping there leaves zero margin for piezo-to-piezo manufacturing
    variation, battery sag at low state-of-charge, or temperature drift.
    170 (~67% duty) sits well below the edge while still giving plenty of
    range above the 50% default. No legitimate use case for the device needs
    duty above 67% — the piezo is tuned for the 50% sweet spot.
    [config.ino]
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2026-05-15 Calm pastel UI redesign + log buffer + plot-mute default (#15)
    * Mute [PLOT] stream by default + populate the in-RAM log buffer
    Two long-standing UX nits:
    1. The [PLOT] CSV stream (for Arduino Serial Plotter) was on by default,
    spamming the USB serial log at PLOT_PRINT_HZ. Most users never look
    at it. Now muted at boot; toggle via web Debug tab or serial `m`.
    2. The web UI Debug "Recent activity log" was empty because the log
    buffer only captures lines written with logPrintln/logPrintf — and
    almost every module used raw Serial.println. Switched the most
    useful events to the log helpers:
    - main: enterIdle/enterRunning/enterTransitionFromRunning
    - main loop: WATER_DE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
    [BlockKit_Production.ino, current_sense.ino, piezo_sense.ino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]
2026-05-15 Hide the periodic disc-removal probe inside the wave's natural trough (#16)
    Reported: in current-sense reed-replacement mode (senseUseAsReed=true),
    the every-5 s disc-removal probe forced PWM to 10 and blocked the loop
    for ~60 ms — visible as a brief mist dip + 3-frame LED freeze.
    Fix: arm-then-defer pattern. On each senseAutoProbeIntervalS interval,
    mark the probe as armed but defer it until waveIntensityAtPiezo() falls
    below ~10 % of its range (gauss < 24). That's already the dimmest moment
    of the wave, so dropping PWM to 10 for the probe lands during a moment
    the user expects the mist to be quiet. Bounded by a 2 s timeout so the
    cadence never drifts even if the trough is slow to arrive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
    [piezo_sense.ino]
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2026-05-15 Add POST /api/cmd/wave-period for live breath-rate updates
    A companion device (e.g. an mmWave breathing sensor) can now push live
    breathing-rate updates without touching NVS. Accepts {"ms":N} (500..60000)
    or {"bpm":N} (1..120) for friendly use from either unit. Mirrors the
    existing /api/cmd/level pattern: RAM-only, validated, requires admin auth.
    Reboot reverts to the persisted default — set a new baseline via
    /api/config if desired. This keeps high-frequency sensor traffic off the
    config blob and protects the NVS sector from wear.
    Compile: 1278086 -> 1278666 bytes (+580), 97% of partition, 0 warnings.
    [web_server.ino]
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2026-05-15 Keep live wave-period out of NVS via separate override var
    Codex review caught a real leak: /api/cmd/wave-period was writing
    cfg.wavePeriodMs directly, but any unrelated /api/config save (e.g.
    toggling mistLedLinked) calls configSave() which packs the *entire*
    cfg blob into NVS — so a transient sensor reading could accidentally
    become the persisted baseline.
    Introduces g_liveWavePeriodMs as a separate non-persisted override.
    waveCenterYQ8() honors it when non-zero, falling back to cfg.wavePeriodMs
    otherwise. The endpoint and status JSON read/write the override; the NVS
    blob is untouched until the user explicitly POSTs to /api/config. Reboot
    clears the override (g_liveWavePeriodMs = 0), re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
    [led_driver.ino, web_server.ino]
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2026-05-15 Use path-specific error messages in /api/cmd/wave-period
    /review caught a UX nit: a client posting {"bpm":121} got the error
    "ms must be 500..60000" even though it never wrote 'ms'. The 121 BPM
    converted to 495 ms and tripped the downstream check, leaking the
    firmware-internal unit. Now each input path validates its own range and
    returns a message matching the key the client actually sent.
    Compile: 1278744 -> 1278798 bytes (+54), 97% of partition, 0 warnings.
    [web_server.ino]
2026-05-24 Add demo mode: 5-tap button gesture toggles WiFi-off operation
    Press the user button five times within 400 ms gaps to flip the device
    between CONFIG mode (default - WiFi/OTA/web up, ready for setup) and
    DEMO mode (WiFi/OTA/web skipped at boot, fully offline). The mode is
    persisted in NVS under "demoOn" so the device returns to whatever mode
    it was last in after a power cycle - handy for trade-show demos where
    a battery swap shouldn't require re-tapping.
    Without this, taking the kit somewhere with no known WiFi caused
    wifiInit() to block on WiFiManager for 3 min and then reboot in a loop
    forever. Demo mode is now the only clean offline path.
    Implementation notes:
    * The 5-tap counter rides o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
    [BlockKit_Production.ino, config.ino, pins.h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]
2026-05-24 Address Codex review: make demo mode reachable from a fresh boot
    Codex P1: on a unit that has never connected to WiFi (or any device taken
    to a venue where its saved AP isn't reachable) the runtime 5-tap handler
    could never fire because wifiInit() blocks inside WiFiManager and reboots
    on portal timeout long before loop() runs. The user's whole point of demo
    mode - "no internet needed, just turn it on and tap 5x" - was unreachable.
    Adds a 3-second boot-time tap window between buttonInit() and wifiInit(),
    only on the CONFIG-mode path. Same gesture as runtime (5 short presses with
    <400 ms gaps); status LED is held at the dim "waiting" duty during the
    window so the user has a visible cue it's o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
    [BlockKit_Production.ino]
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
